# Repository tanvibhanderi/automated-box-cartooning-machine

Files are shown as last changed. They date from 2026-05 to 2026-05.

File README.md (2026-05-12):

# 📦 Automated Box Cartooning Machine
### Embedded Mechatronics System — Tiva C Microcontroller, Pneumatics, SolidWorks & AutoCAD









---

## 📌 Overview

A fully automated, low-cost **box cartooning machine** designed and built from scratch for small to medium-sized manufacturers. The system autonomously picks, rotates, folds, and locks cardboard box flaps using a custom-designed mechatronics system — all controlled by a single **TM4C123 microcontroller**.

Built for *MENG-2500 Mechatronics Project* at Humber Polytechnic — Winter 2025.

> 👩‍💻 **Author:** Tanvi Bhanderi — Mechatronics Engineering

---

## 🖼️ System Demo

| Physical Build | SolidWorks Assembly |
|---|---|
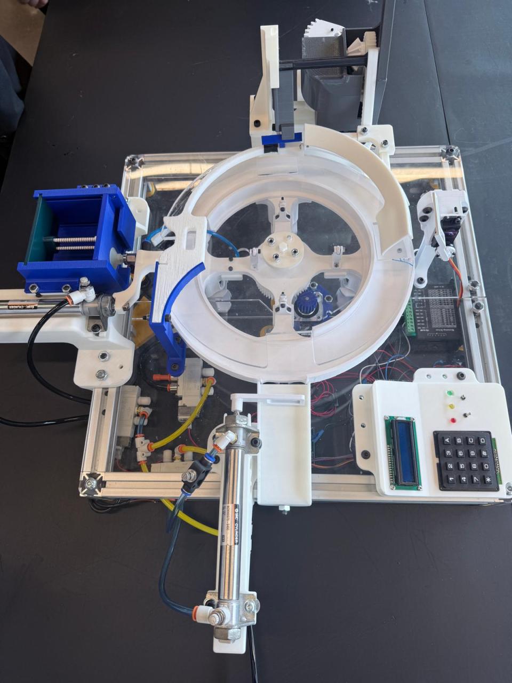
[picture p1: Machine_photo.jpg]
Machine
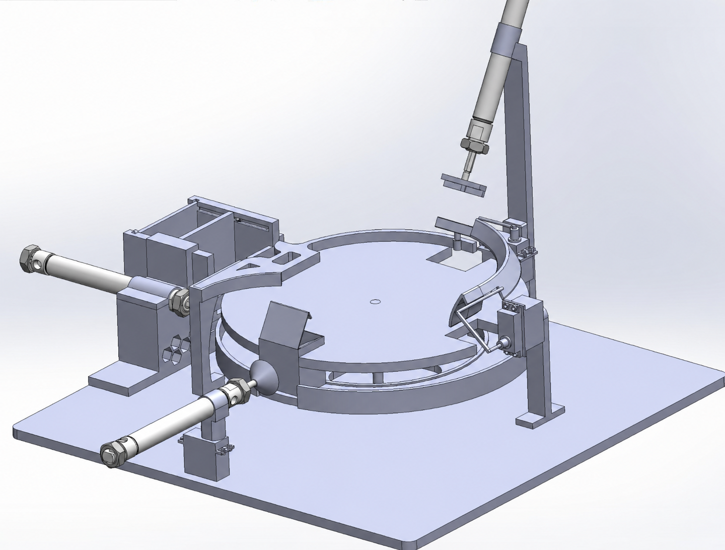
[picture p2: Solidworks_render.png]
CAD
|  |  |

---

## ✨ Key Features

- ✅ **4-phase automated operation** — pick, rotate, fold, lock
- ✅ **Closed-loop control** via ultrasonic sensor feedback
- ✅ **Operator interface** — 4×4 keypad + 16×2 I2C LCD display
- ✅ **Pneumatic actuation** — double-acting cylinders + vacuum suction cup
- ✅ **Custom SolidWorks design** — fully 3D printed and assembled
- ✅ **Under $300 budget** — scalable for real manufacturing use

---

## 🏗️ System Architecture

```
Operator Input (Keypad)
        │
        ▼
TM4C123GH6PM Microcontroller
        │
   ┌────┼──────────────────────────────┐
   │    │                              │
   ▼    ▼                              ▼
Stepper  Servo Motors (x2)      Solenoid Valves
Motor    (Flap Folding)         (Pneumatic Control)
   │                                   │
   ▼                                   ▼
Revolving Disc              Double-Acting Cylinders
(Box Transport)             + Venturi Vacuum Cup
                                       │
                            ┌──────────┴──────────┐
                            ▼                     ▼
                       Box Pickup            Box Ejection
                       
        ↑ Ultrasonic Sensor (HC-SR04) — position feedback
        ↑ LCD Display — status output
```

---

## ⚙️ 4-Phase Operation

| Phase | Action | Actuators Used |
|---|---|---|
| **Phase 1** | Box blank pickup from stack | Vacuum cup + pneumatic cylinder |
| **Phase 2** | Box transport & rotation | NEMA 17 stepper + revolving disc |
| **Phase 3** | Flap folding | MG996R servo motors |
| **Phase 4** | Flap locking & ejection | Pneumatic cylinder |

---

## 🔧 Technical Components

### Electrical

| Component | Part | Function |
|---|---|---|
| Microcontroller | TM4C123GH6PM (Tiva C) | Main logic & control |
| Stepper Motor | NEMA 17 + DM542 Driver | Revolving disc rotation |
| Servo Motors | MG996R (×2) | Flap folding mechanism |
| Sensor | HC-SR04 Ultrasonic | Object detection & positioning |
| Display | I2C LCD 16×2 | Status & user feedback |
| Input | 4×4 Matrix Keypad | Box count & operator control |
| Power | LM2596 Buck Converter | 5V regulation for logic components |
| Switching | 5V Relay Module | Solenoid valve control |

### Pneumatic

| Component | Spec | Function |
|---|---|---|
| Double-Acting Cylinders | Bore: 0.75in, Stroke: 4in | Box pickup & ejection |
| 5/2 Solenoid Valve | Spring return | Airflow direction control |
| Venturi Vacuum Generator | Compressed air powered | Suction generation |
| Flat Suction Cup | 25mm | Grips flat cardboard blank |

---

## 🖥️ SolidWorks Design

The full machine was designed in **SolidWorks** before fabrication. Parts were 3D printed and assembled on an aluminum extrusion frame.

### Assembly Structure

```
FINAL MAIN ASSEMB.SLDASM
├── REVOLVING DISC ASSEMB.SLDASM     — central rotating platform
├── PHASE_1.SLDASM                   — pickup mechanism
├── PHASE 2 ASSEMB.SLDASM            — transport & rotation
├── LOCK FOLDING ASSEMB.SLDASM       — flap folding arms
├── PHASE 4 ASSEMB.SLDASM            — ejection mechanism
├── BASE EXTRUSION ASSEMB.SLDASM     — aluminum frame base
└── CONTROL_INTERFACE.SLDPRT        — keypad/LCD panel
```

> The full SolidWorks assembly (`.SLDASM`) and all part files (`.SLDPRT`) are included in this repository.

---

## 📐 AutoCAD Manufacturing Drawings

All machine parts were drafted in **AutoCAD** for precise fabrication before being built. The `.DWG` files contain dimensioned 2D drawings used for laser cutting and CNC machining.

| File | Part |
|---|---|
| `final_box_cut_out.DWG` | Box blank cutout template |
| `MAIN_REVOLVING_DISC.DWG` | Central rotating disc |
| `LOWER_BASE_HALF.DWG` | Base plate — lower half |
| `LOWER_BASE_HALF_2.DWG` | Base plate — lower half variant |
| `TOP_BASE_CI_SIDE.DWG` | Top base — cylinder interface side |
| `TOP_BASE_MOTOR_SIDE.DWG` | Top base — motor mount side |
| `MOTOR_PLATE.DWG` | Stepper motor mounting plate |

---

## 📁 Repository Structure

```
📦 automated-box-cartooning-machine/
├── 📁 firmware/
│   └── main.c                       # Tiva C embedded C firmware
├── 📁 autocad/
│   ├── final_box_cut_out.DWG        # Box blank cutout template
│   ├── MAIN_REVOLVING_DISC.DWG      # Revolving disc drawing
│   ├── LOWER_BASE_HALF.DWG          # Base plate drawings
│   ├── LOWER_BASE_HALF_2.DWG
│   ├── TOP_BASE_CI_SIDE.DWG         # Top base drawings
│   ├── TOP_BASE_MOTOR_SIDE.DWG
│   └── MOTOR_PLATE.DWG              # Motor mount plate
├── 📁 assets/
│   ├── machine_photo.jpg            # Physical build photo
│   ├── solidworks_render.jpg        # SolidWorks assembly render
│   └── circuit_schematic.jpg        # Circuit wiring diagram
├── [SolidWorks .SLDPRT / .SLDASM files]
├── 📄 Final_Project_Report.pdf
└── 📄 README.md
```

> Open `FINAL MAIN ASSEMB.SLDASM` as the top-level SolidWorks assembly. Firmware compiles in Keil uVision or TI Code Composer Studio targeting TM4C123GH6PM.

---

## 🚀 Build & Flash Firmware

```bash
# Open in Keil uVision or TI Code Composer Studio
# Target: TM4C123GH6PM @ 16 MHz

# 1. Open firmware/main.c
# 2. Add TM4C123GH6PM.h to project (TI DriverLib or CMSIS)
# 3. Build → Flash via ICDI debugger on LaunchPad
```

**Key firmware functions:**

| Function | Description |
|---|---|
| `RotateMotor(angle, speed, dir)` | Steps NEMA 17 by exact degrees |
| `Servo_Set_Angle(pulse, pin)` | PWM bit-bang to MG996R servo |
| `DCV_Set(mask)` | Controls solenoid valves (active-low) |
| `Delay_MicroSecond(time)` | Hardware Timer1A precision delay |

---

- Designing a **multi-subsystem mechatronics machine** from concept to physical build
- Programming **embedded C++** on a TM4C123 microcontroller — timers, GPIO, PWM, UART
- Integrating **pneumatic systems** with electronic control — solenoid valves, cylinders, vacuum
- Building a full **SolidWorks assembly** with 40+ custom parts, designed for 3D printing
- Creating **AutoCAD manufacturing drawings** (`.DWG`) with dimensions for fabrication
- Implementing **closed-loop feedback** using ultrasonic sensors for position detection
- Working within a **$300 hardware budget** — component selection, sourcing, and tradeoffs

---

## 🔮 Future Improvements

- Add **IoT remote monitoring** for production tracking
- Implement **parameterized box sizing** — adjustable for multiple carton dimensions
- Replace open-loop stepper with **encoder feedback** for precise positioning
- Add **fault detection** — jam detection and automatic recovery logic

---

## 📚 References

- TM4C123GH6PM Datasheet — Texas Instruments
- MG996R Servo Datasheet — Tower Pro
- HC-SR04 Ultrasonic Sensor Datasheet — SparkFun
- NEMA 17 + DM542 Driver Documentation
- Humber Polytechnic MENG-2500 — Mechatronics Project, Winter 2025

---

<p align="center">
  Built by Tanvi Bhanderi · Humber Polytechnic — Mechatronics Engineering
</p>

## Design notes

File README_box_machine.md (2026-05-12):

# 📦 Automated Box Cartooning Machine
### Embedded Mechatronics System — TM4C123 Microcontroller, Pneumatics & SolidWorks








---

## 📌 Overview

A fully automated, low-cost **box cartooning machine** designed and built from scratch for small to medium-sized manufacturers. The system autonomously picks, rotates, folds, and locks cardboard box flaps using a custom-designed mechatronics system — all controlled by a single **TM4C123 microcontroller**.

Built for *MENG-2500 Mechatronics Project* at Humber Polytechnic — Winter 2025.

> 👩‍💻 **Author:** Tanvi Bhanderi — Mechatronics Engineering

---

## 🖼️ System Demo

| Physical Build | SolidWorks Assembly |
|---|---|
| Machine | CAD |

---

## ✨ Key Features

- **4-phase automated operation** — pick, rotate, fold, lock
- **Closed-loop control** via ultrasonic sensor feedback
- **Operator interface** — 4×4 keypad + 16×2 I2C LCD display
- **Pneumatic actuation** — double-acting cylinders + vacuum suction cup
- **Custom SolidWorks design** — fully 3D printed and assembled
- **Under $300 budget** — scalable for real manufacturing use

---

## 🏗️ System Architecture

```
Operator Input (Keypad)
        │
        ▼
TM4C123GH6PM Microcontroller
        │
   ┌────┼──────────────────────────────┐
   │    │                              │
   ▼    ▼                              ▼
Stepper  Servo Motors (x2)      Solenoid Valves
Motor    (Flap Folding)         (Pneumatic Control)
   │                                   │
   ▼                                   ▼
Revolving Disc              Double-Acting Cylinders
(Box Transport)             + Venturi Vacuum Cup
                                       │
                            ┌──────────┴──────────┐
                            ▼                     ▼
                       Box Pickup            Box Ejection
                       
        ↑ Ultrasonic Sensor (HC-SR04) — position feedback
        ↑ LCD Display — status output
```

---

## ⚙️ 4-Phase Operation

| Phase | Action | Actuators Used |
|---|---|---|
| **Phase 1** | Box blank pickup from stack | Vacuum cup + pneumatic cylinder |
| **Phase 2** | Box transport & rotation | NEMA 17 stepper + revolving disc |
| **Phase 3** | Flap folding | MG996R servo motors |
| **Phase 4** | Flap locking & ejection | Pneumatic cylinder |

---

## 🔧 Technical Components

### Electrical

| Component | Part | Function |
|---|---|---|
| Microcontroller | TM4C123GH6PM (Tiva C) | Main logic & control |
| Stepper Motor | NEMA 17 + DM542 Driver | Revolving disc rotation |
| Servo Motors | MG996R (×2) | Flap folding mechanism |
| Sensor | HC-SR04 Ultrasonic | Object detection & positioning |
| Display | I2C LCD 16×2 | Status & user feedback |
| Input | 4×4 Matrix Keypad | Box count & operator control |
| Power | LM2596 Buck Converter | 5V regulation for logic components |
| Switching | 5V Relay Module | Solenoid valve control |

### Pneumatic

| Component | Spec | Function |
|---|---|---|
| Double-Acting Cylinders | Bore: 0.75in, Stroke: 4in | Box pickup & ejection |
| 5/2 Solenoid Valve | Spring return | Airflow direction control |
| Venturi Vacuum Generator | Compressed air powered | Suction generation |
| Flat Suction Cup | 25mm | Grips flat cardboard blank |

---

## 🖥️ SolidWorks Design

The full machine was designed in **SolidWorks** before fabrication. Parts were 3D printed and assembled on an aluminum extrusion frame.

### Assembly Structure

```
FINAL MAIN ASSEMB.SLDASM
├── REVOLVING DISC ASSEMB.SLDASM     — central rotating platform
├── PHASE_1.SLDASM                   — pickup mechanism
├── PHASE 2 ASSEMB.SLDASM            — transport & rotation
├── LOCK FOLDING ASSEMB.SLDASM       — flap folding arms
├── PHASE 4 ASSEMB.SLDASM            — ejection mechanism
├── BASE EXTRUSION ASSEMB.SLDASM     — aluminum frame base
└── CONTROL_INTERFACE.SLDPRT        — keypad/LCD panel
```

> The full SolidWorks assembly (`.SLDASM`) and all part files (`.SLDPRT`) are included in this repository.

---

## 📁 Repository Structure

```
📦 automated-box-cartooning-machine/
├── 📁 firmware/
│   └── main.c                       # TM4C123 embedded C firmware — full machine control
├── 📁 solidworks/
│   └── FINAL_MAIN_ASSEMB.zip        # Complete SolidWorks assembly + all part files
├── 📁 assets/
│   ├── machine_photo.jpg            # Physical build photo
│   ├── solidworks_render.jpg        # SolidWorks assembly render
│   └── circuit_schematic.jpg        # Full circuit wiring diagram
├── 📄 Final_Project_Report.pdf      # Full project report
└── 📄 README.md
```

> Open `FINAL MAIN ASSEMB.SLDASM` as the top-level SolidWorks assembly. Firmware compiles in Keil uVision or TI Code Composer Studio targeting TM4C123GH6PM.

---

## 🚀 Build & Flash Firmware

```bash
# Open in Keil uVision or TI Code Composer Studio
# Target: TM4C123GH6PM @ 16 MHz

# 1. Open firmware/main.c
# 2. Add TM4C123GH6PM.h to project (TI DriverLib or CMSIS)
# 3. Build → Flash via ICDI debugger on LaunchPad
```

**Key firmware functions:**

| Function | Description |
|---|---|
| `RotateMotor(angle, speed, dir)` | Steps NEMA 17 by exact degrees |
| `Servo_Set_Angle(pulse, pin)` | PWM bit-bang to MG996R servo |
| `DCV_Set(mask)` | Controls solenoid valves (active-low) |
| `Delay_MicroSecond(time)` | Hardware Timer1A precision delay |

---

- Designing a **multi-subsystem mechatronics machine** from concept to physical build
- Programming **embedded C++** on a TM4C123 microcontroller — timers, GPIO, PWM, UART
- Integrating **pneumatic systems** with electronic control — solenoid valves, cylinders, vacuum
- Building a full **SolidWorks assembly** with 40+ custom parts, designed for 3D printing
- Implementing **closed-loop feedback** using ultrasonic sensors for position detection
- Working within a **$300 hardware budget** — component selection, sourcing, and tradeoffs

---

## 🔮 Future Improvements

- Add **IoT remote monitoring** for production tracking
- Implement **parameterized box sizing** — adjustable for multiple carton dimensions
- Replace open-loop stepper with **encoder feedback** for precise positioning
- Add **fault detection** — jam detection and automatic recovery logic

---

## 📚 References

- TM4C123GH6PM Datasheet — Texas Instruments
- MG996R Servo Datasheet — Tower Pro
- HC-SR04 Ultrasonic Sensor Datasheet — SparkFun
- NEMA 17 + DM542 Driver Documentation
- Humber Polytechnic MENG-2500 — Mechatronics Project, Winter 2025

---

<p align="center">
  Built by Tanvi Bhanderi · Humber Polytechnic — Mechatronics Engineering
</p>

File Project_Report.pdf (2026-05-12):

Course Number | MENG-2500
Course Title | Mechatronics Project
Semester/Year | 2025
Lab/Tutorial Report No. | Final Report
Title of the Experiment | Final Project Report
Instructor Name | Mehrdad Tabrizipour
Section No. | ONB
Submission Date | 4/22/2025
Due Date | 4/22/2025
Student Name | ID
TANVI BHANDERI | N01605037
GURSHAN SINGH | N01604467
HRISHIKESH PATEL | N01609756
ASSADULLAH JIN | N01626920
SOKRAT KRISTULLA | N01655524

* By signing above, you attest that you have contributed to this submission and confirm that all work you have contributed to this submission is your work. Any suspicion of copying or plagiarism in this work will result in an investigation of Academic Misconduct and may result in a ZERO on the work or possibly more severe penalties. https://academic-regulations.humber.ca/2021-2022/17.0-ACADEMIC-MISCONDUCT

## Introduction

### In manufacturing, automation is essential for increasing productivity and lowering human error. The goal of this project is to use embedded microcontroller devices to automate the box cartooning process. It targets manufacturers on a budget that are searching for a dependable and

scalable solution.

## Abstract

In this project, an automated cartooning machine that uses embedded technology is designed and put into operation. The objective is to create a small-scale, affordable solution for manufacturers. Pneumatic cylinders, a keypad, an LCD, sensors, servo motors, and a stepper motor are all controlled by a TM4C123GH6PM microcontroller. It has four operating phases and can automatically fold and lock box flaps. A closed-loop control

system is used by the machine to ensure accuracy and dependability.

## Problem Overview and Scope Statement

Manual box folding is labor-intensive, inconsistent, and inefficient in small to medium-sized businesses. The goal of this project is to create a device that uses actuators and sensor feedback to autonomously fold and lock box flaps. The solution needs to be small, flexible, and reasonably priced (within

a $300 budget).

## CODE

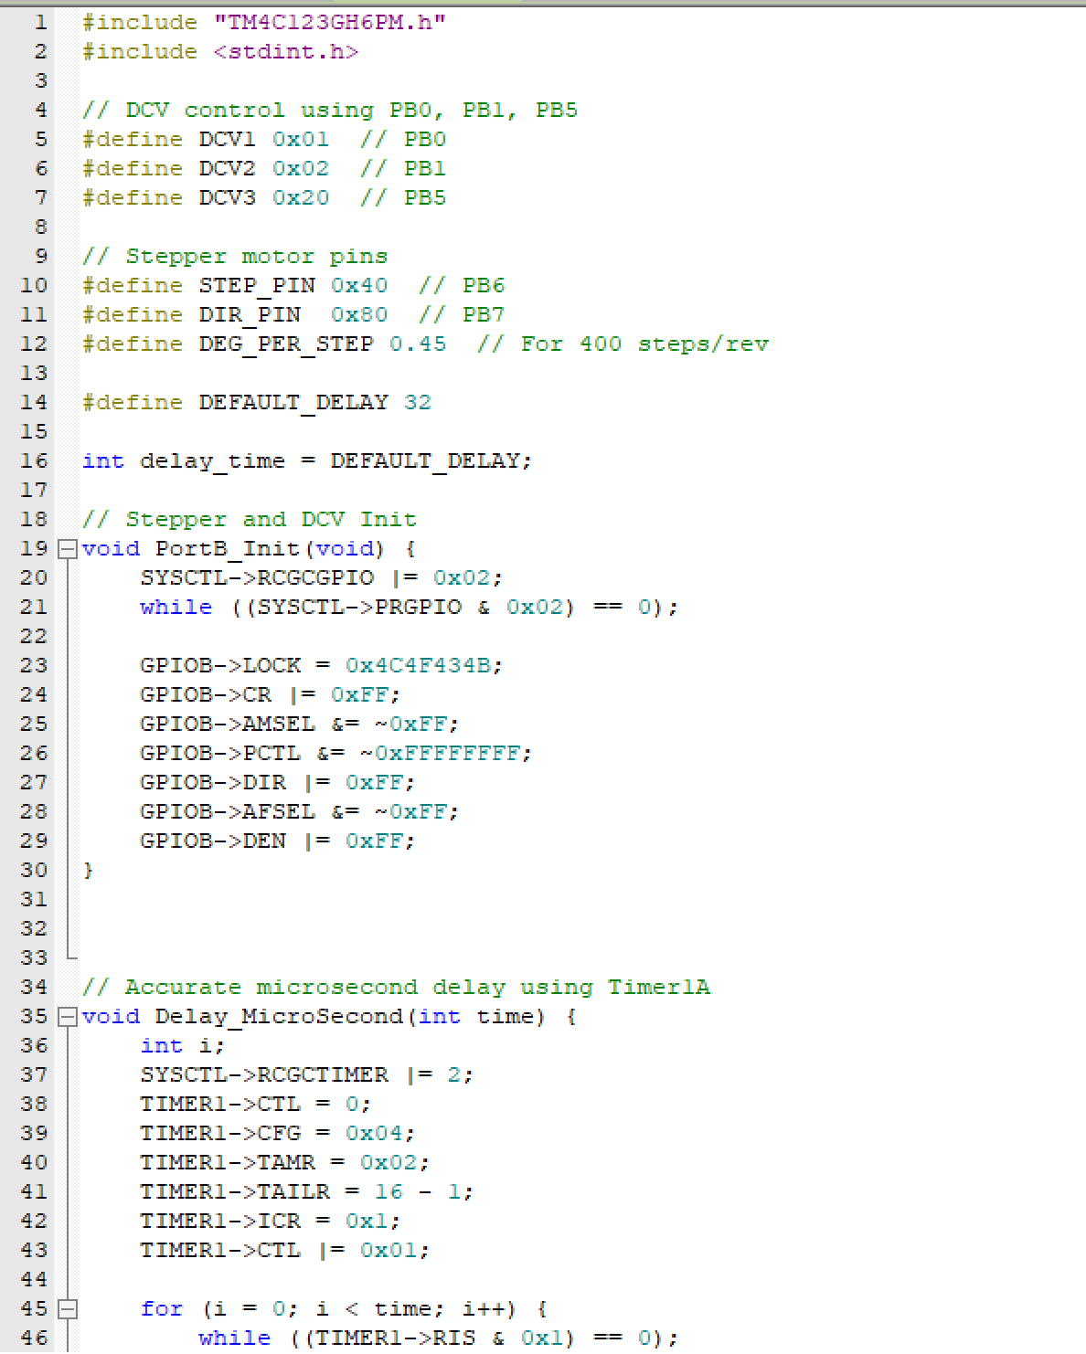
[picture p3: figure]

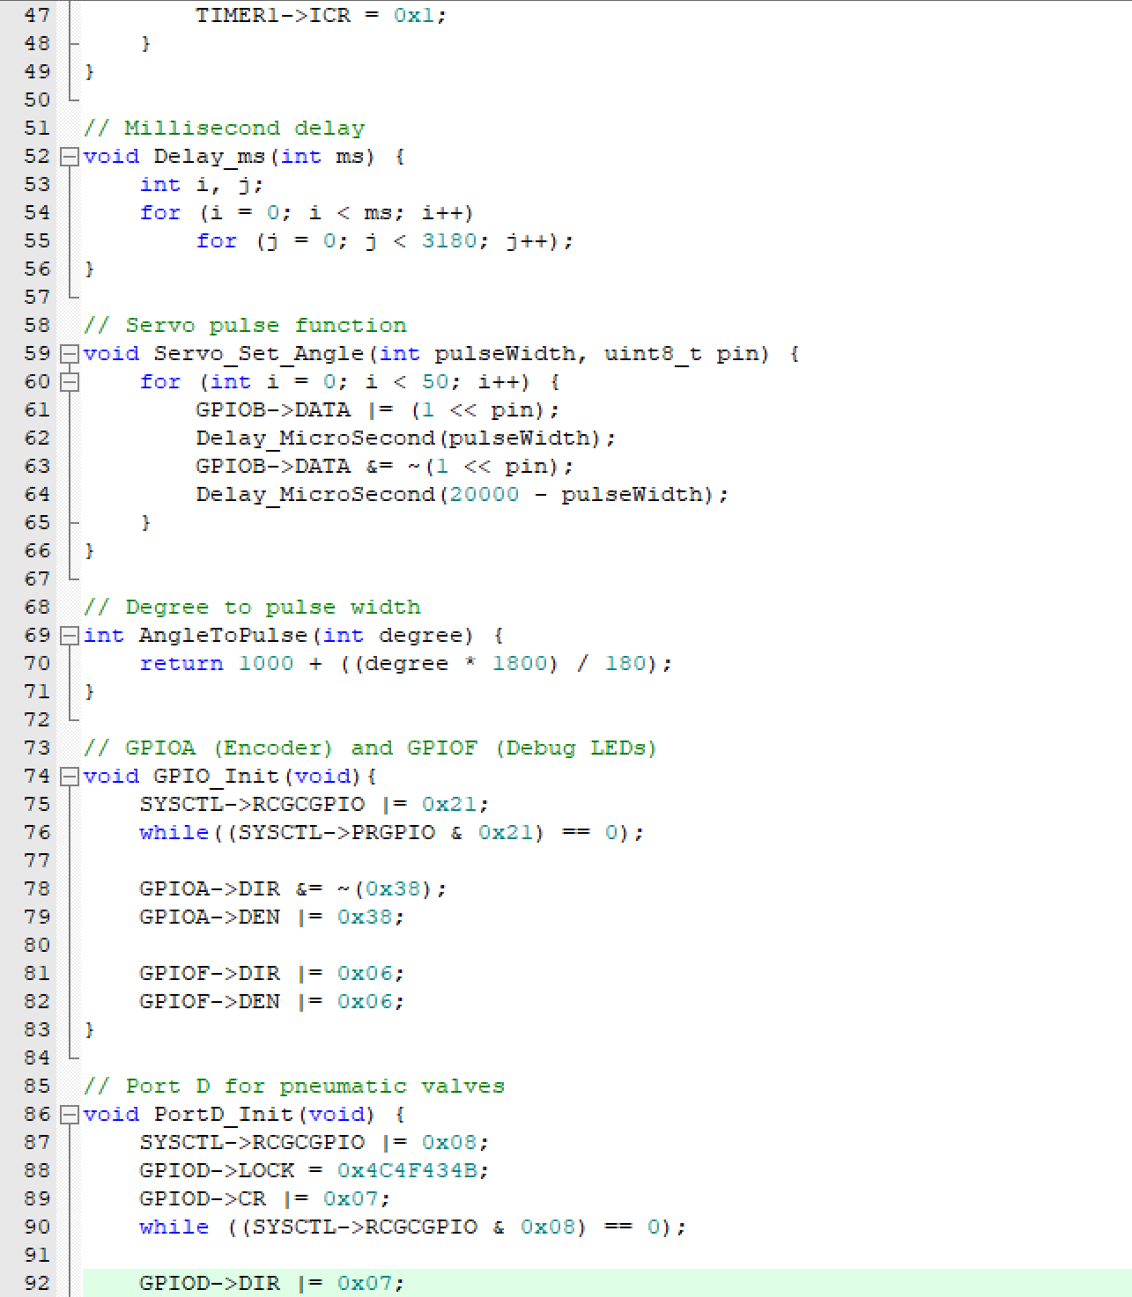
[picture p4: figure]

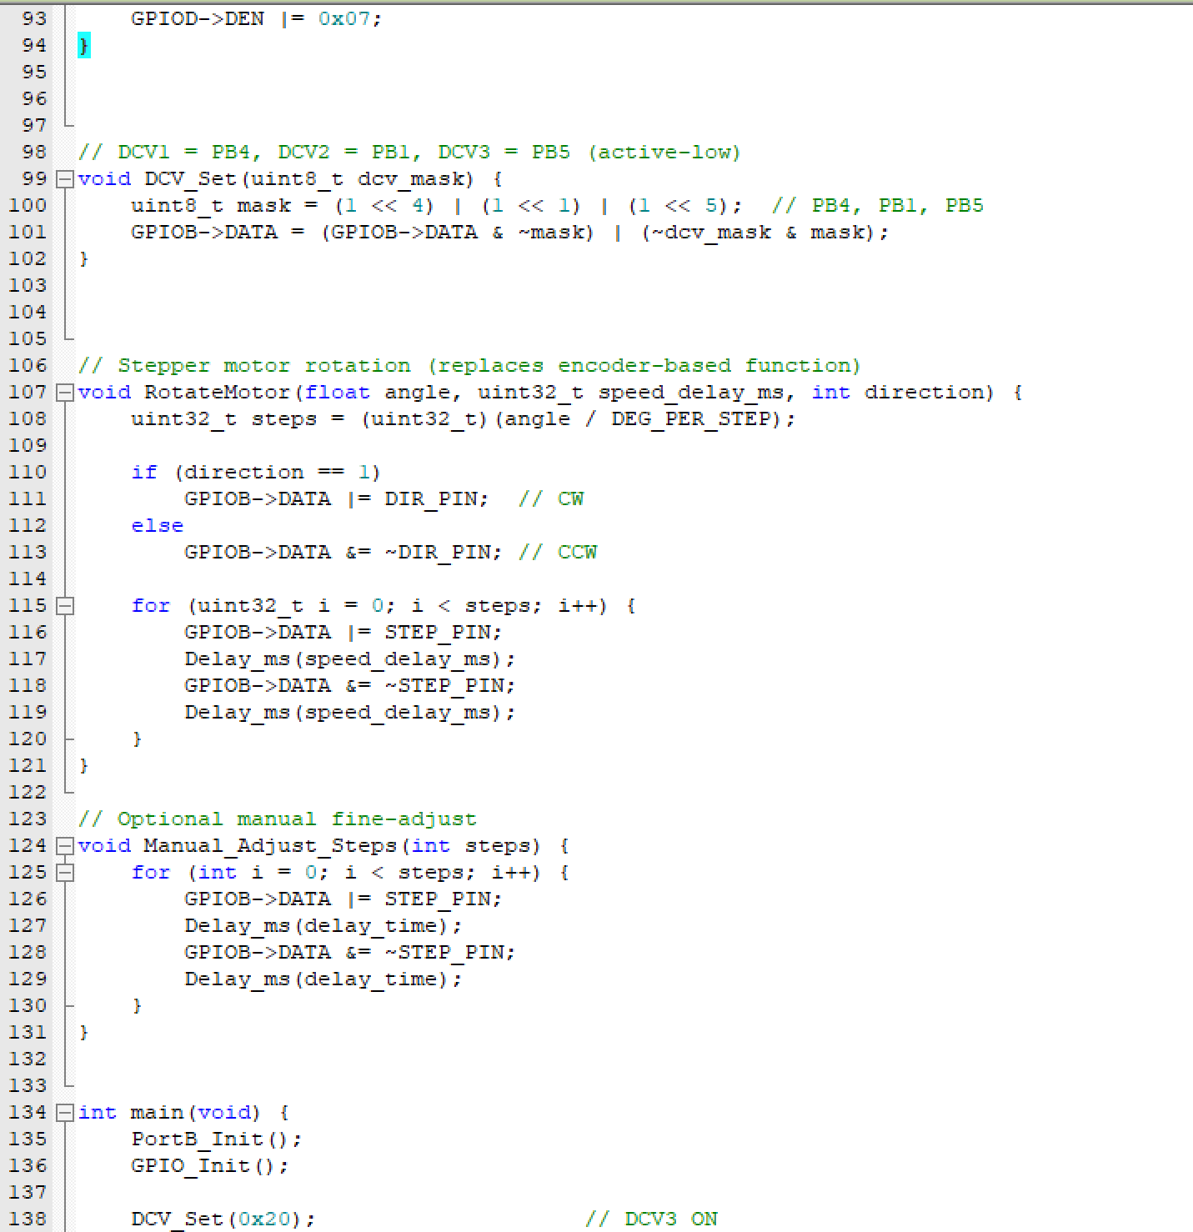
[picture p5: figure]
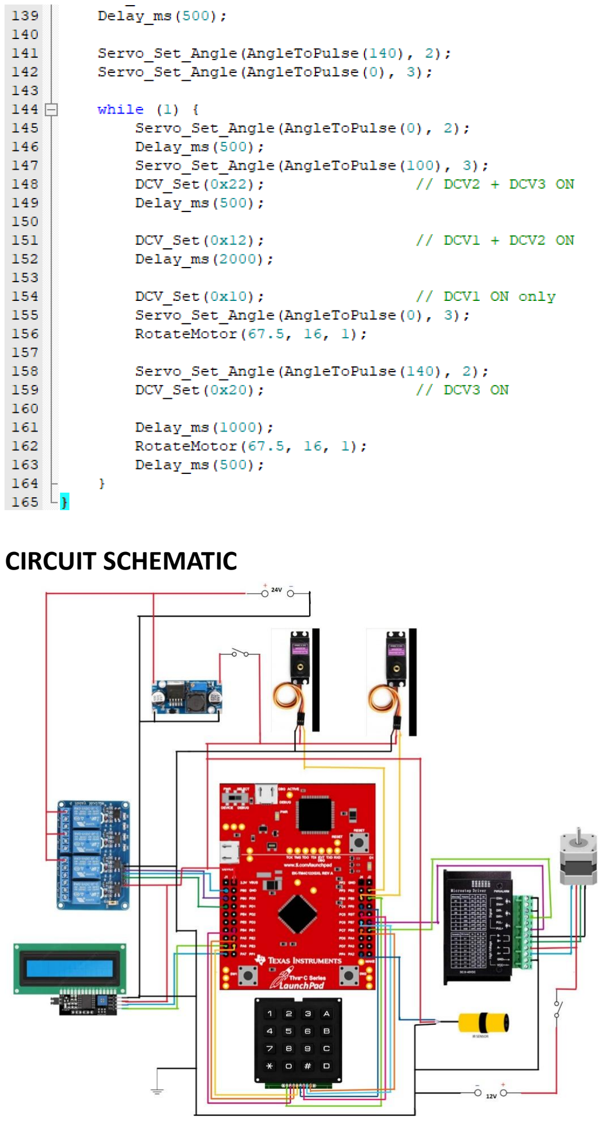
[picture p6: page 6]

## CIRCUIT SCHEMATIC

### 1. Electrical Components

### TIVA C LaunchPad (TM4C123GXL)

Function: Microcontroller board used for logic and control

Datasheet: https://www.ti.com/lit/ds/symlink/tm4c123gh6pm.pdf

Function: Controls solenoid valves and vacuum generator

Datasheet: https://www.circuitbasics.com/wp-content/uploads/2015/11/SRD-05VDC-SL-C-Datasheet.pdf (https://www.circuitbasics.com/wp-content/uploads/2015/11/SRD-05VDC-SL-C-Datasheet.pdf)

### MG996R Servo Motor

Function: Used for flap folding mechanism

Datasheet: https://www.electronicoscaldas.com/datasheet/MG996R_Tower-Pro.pdf

### 4x4 Matrix Keypad

Function: Used for inputting box count or control signals

Datasheet: https://cdn.sparkfun.com/assets/f/f/a/5/0/DS-16038.pdf

### I2C LCD Display (16x2)

Function: Displays status and user feedback

Datasheet: https://www.handsontec.com/dataspecs/module/I2C_1602_LCD.pdf

### NEMA 17 Stepper Motor

Function: Used for pushing or rotating boxes

Datasheet: https://pages.pbclinear.com/rs/909-BFY-775/images/Data-Sheet-Stepper-Motor-Support.pdf (https://pages.pbclinear.com/rs/909-BFY-775/images/Data-Sheet-Stepper-Motor-Support.pdf)

### Stepper Motor Driver (DM542)

Function: Drives the NEMA 17 motor

Datasheet: https: https://kitaez-cnc.com/f/dm542.pdf

### Ultrasonic Sensor (HC-SR04)

Function: Detects object presence or distance

Datasheet: https://cdn.sparkfun.com/datasheets/Sensors/Proximity/HCSR04.pdf

### LM2596 Buck Converter

Function: Steps down voltage to 5V for low-power components

Datasheet: https://www.ti.com/lit/ds/symlink/lm2596.pdf

### 2. Pneumatic Components

### Double-Acting Cylinders

Function: Used for pickup and ejection. Bore: 0.75in, Rod: 0.25in, Stroke: 4in

Datasheet: https://ngsgi.com/pdfs/cip_da_cylinders_specs.pdf

### 5/2 Solenoid Valve (Spring Return)

Function: Controls airflow direction for cylinder extension/retraction

Datasheet: https://www.uflowvalve.com/pneumatic-valve/product/5-2-single-solenoid-valvewith-spring-return (https://www.uflowvalve.com/pneumatic-valve/product/5-2-single-solenoid-valve-with-spring-return)

### Venturi Vacuum Generator

Function: Generates vacuum using compressed air for suction cup

Datasheet: https://cdn.norgren.com/pdf/CylindricalVenturiVacuumGenerators.pdf

### Flat Suction Cup (25mm)

Function: Grips flat paperboard carton using vacuum

Datasheet: https://www.vacmotion.com/Details.aspx?Cat=Suctioncups&Id=711

## Conclusion and Future Plans

This project effectively used embedded systems to create a cost-effective cartooning machine. It offers packaging applications a scalable automated option. Plans call for integrating IoT technologies for remote monitoring and using parameterized control logic to modify the design to fit different box

sizes.

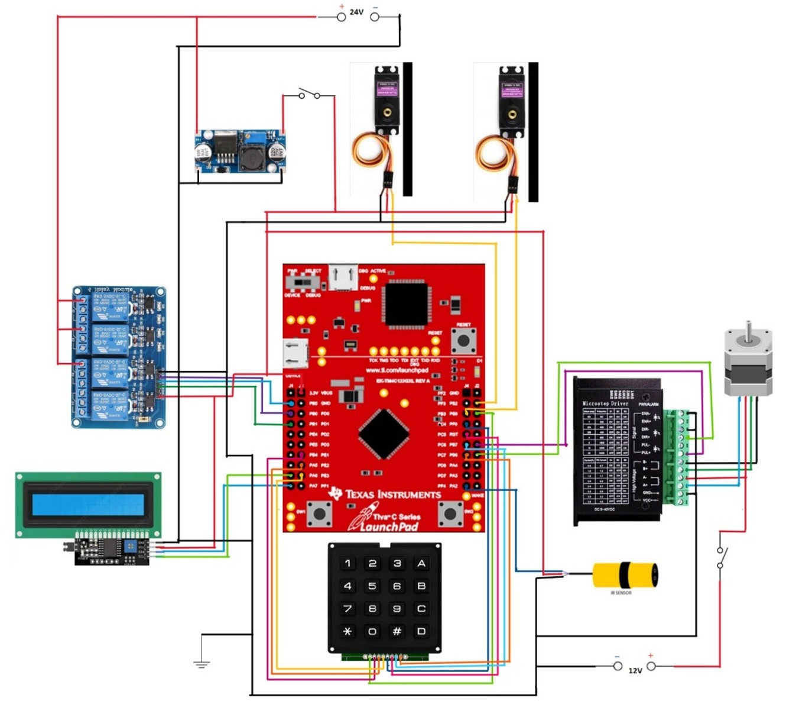
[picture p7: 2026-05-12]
circuit_schematic.jpg

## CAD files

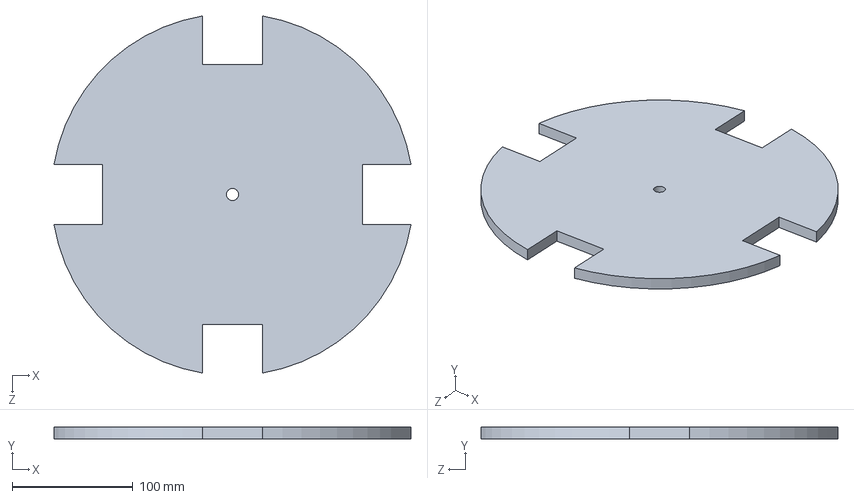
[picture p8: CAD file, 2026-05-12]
MAIN REVOLVING DISC.SLDPRT
295.8 x 10.0 x 295.8 mm

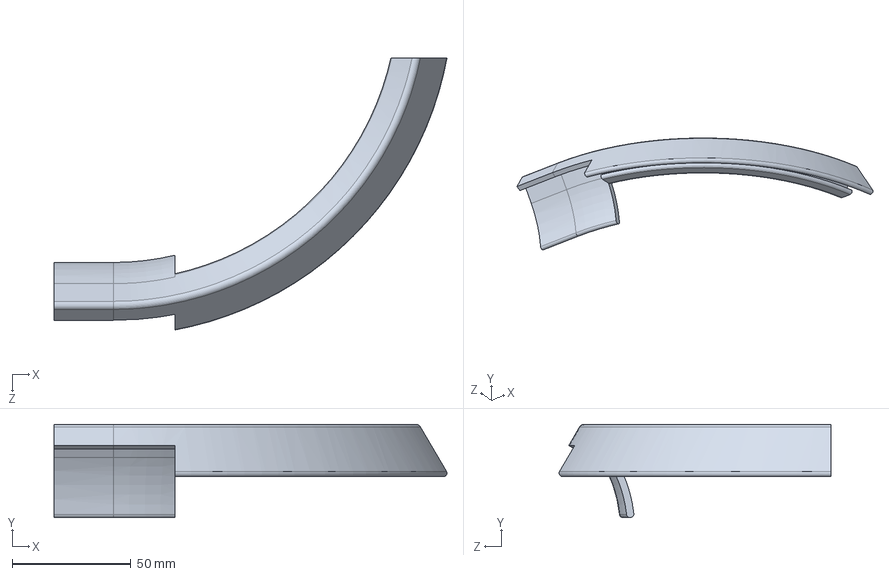
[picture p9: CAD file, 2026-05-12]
lock_folding.SLDPRT
165.4 x 39.2 x 114.4 mm

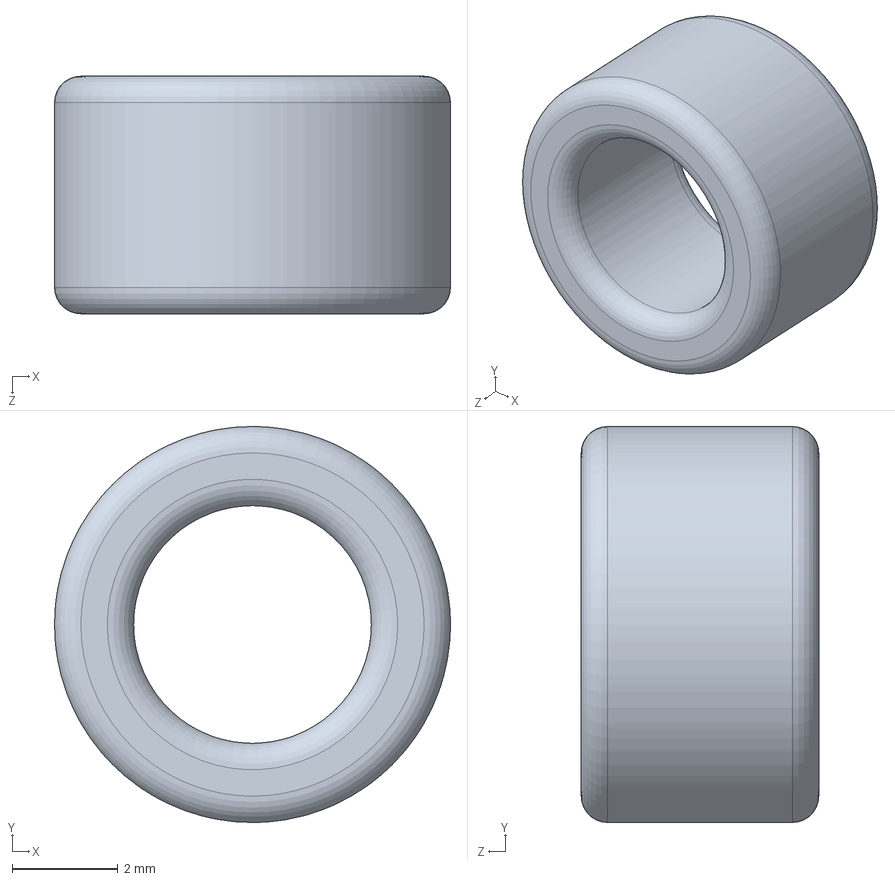
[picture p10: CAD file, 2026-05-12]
wheels.SLDPRT
7.50 x 7.50 x 4.50 mm

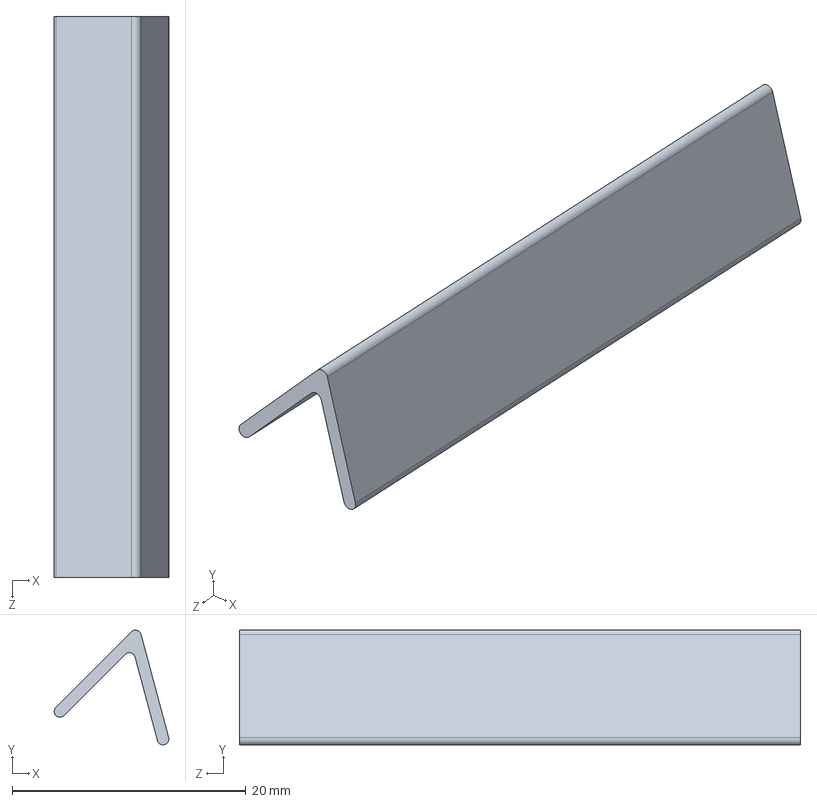
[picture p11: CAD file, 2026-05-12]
Part3.SLDPRT
9.82 x 9.82 x 48.0 mm

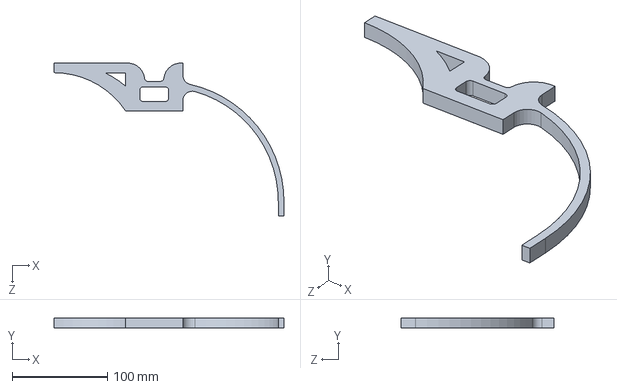
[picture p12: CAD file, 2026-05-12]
Part2.SLDPRT
241.0 x 10.0 x 160.0 mm

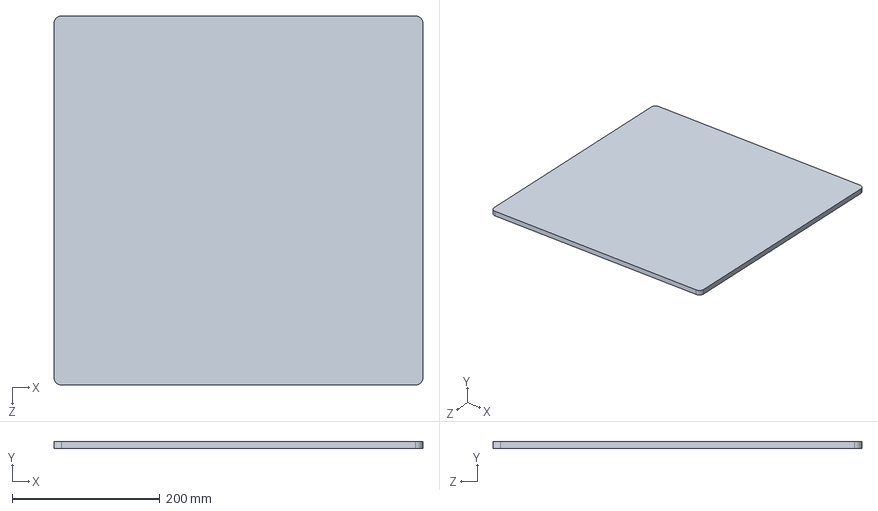
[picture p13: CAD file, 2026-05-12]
BASE PLATE.SLDPRT
500.0 x 10.0 x 500.0 mm

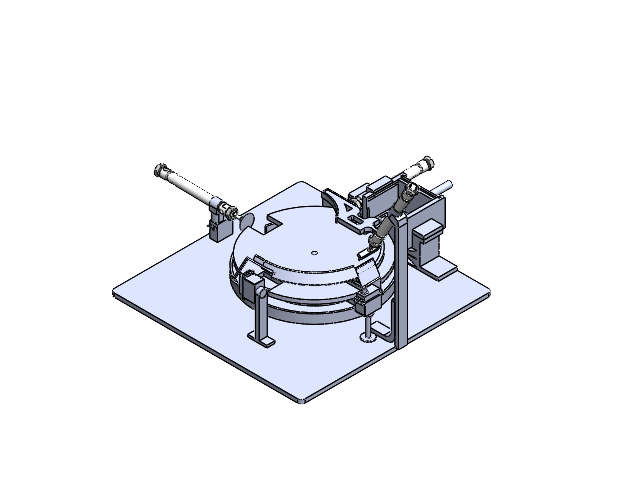
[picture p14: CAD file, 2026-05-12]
MAIN ASSEMBLY.SLDASM
BASE PLATE
MAIN REVOLVING DISC
Part6^MAIN ASSEMBLY
Part7^MAIN ASSEMBLY
Part11^MAIN ASSEMBLY
Part14^MAIN ASSEMBLY
Part15^MAIN ASSEMBLY
Part16^MAIN ASSEMBLY
Part17^MAIN ASSEMBLY x 2
Part26^MAIN ASSEMBLY
Part28^MAIN ASSEMBLY
Part29^MAIN ASSEMBLY
Part30^MAIN ASSEMBLY
Part31^MAIN ASSEMBLY
lock_folding
Part33^MAIN ASSEMBLY
Part35^MAIN ASSEMBLY
Part37^MAIN ASSEMBLY x 3
Part38^MAIN ASSEMBLY x 2
outer_cover
pushing_plate
wheels x 8
moving_plate
spring_cylinders
Part39^MAIN ASSEMBLY
Part40^MAIN ASSEMBLY
Part41^MAIN ASSEMBLY
Part42^MAIN ASSEMBLY
Part43^MAIN ASSEMBLY
Revolving Disc Support x 4
Part1^Stat Disc with Supports x 4
STATIC DISC

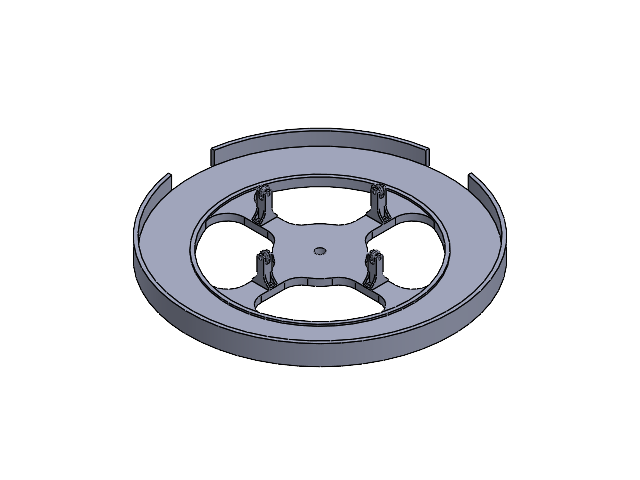
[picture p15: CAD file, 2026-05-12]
Stat Disc with Supports.SLDASM
Revolving Disc Support x 4
Part1^Stat Disc with Supports x 4
STATIC DISC

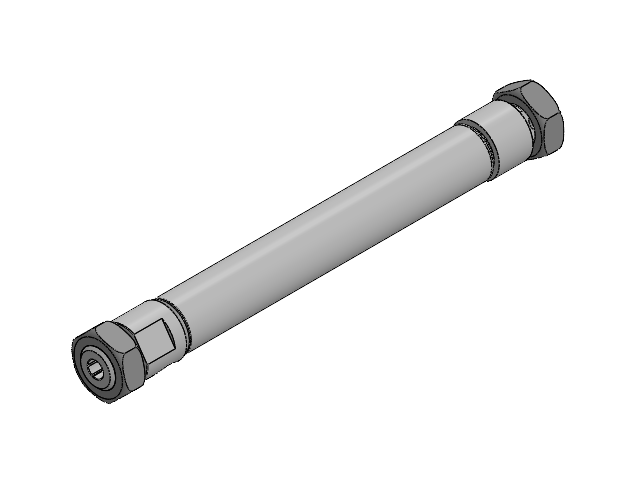
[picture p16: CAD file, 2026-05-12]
pneumatic cylinder.SLDASM


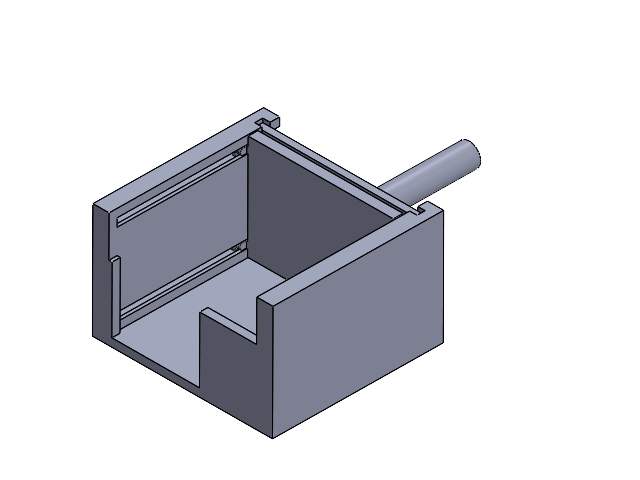
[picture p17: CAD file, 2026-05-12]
NEW_BOX_STACKER.SLDASM
outer_cover
pushing_plate

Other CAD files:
LOWER_BASE_HALF.DWG
LOWER_BASE_HALF_2.DWG
TOP_BASE_MOTOR_SIDE.DWG
MOTOR_PLATE.DWG
TOP_BASE_CI_SIDE.DWG
final box cut out.DWG
Revolving Disc Support.SLDPRT
moving_plate.SLDPRT
05870993_01.SLDPRT
05870993_02.SLDPRT
05870993_03.SLDPRT
05870993_04.SLDPRT
05870993_05.SLDPRT
05870993_06.SLDPRT
MAIN REVOLVING DISC.DWG
STATIC DISC.SLDPRT
outer_cover.SLDPRT
pushing_plate.SLDPRT
spring_cylinders.SLDPRT

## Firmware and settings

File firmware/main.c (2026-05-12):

/*
 * Automated Box Cartooning Machine — Firmware
 * Platform : TM4C123GH6PM (Tiva C LaunchPad)
 * Author   : Tanvi Bhanderi
 * Course   : MENG-2500 Mechatronics Project, Humber Polytechnic — Winter 2025
 *
 * Description:
 *   Controls a 4-phase automated box folding machine using:
 *   - NEMA 17 stepper motor (revolving disc transport)
 *   - MG996R servo motors x2 (flap folding)
 *   - 3x pneumatic DCV solenoid valves (pickup & ejection)
 *   - Venturi vacuum generator (suction cup)
 *
 * Pin Mapping:
 *   Port B: Stepper (PB6=STEP, PB7=DIR), DCVs (PB0, PB1, PB5)
 *   Port A: Encoder inputs (PA3, PA4, PA5)
 *   Port D: Pneumatic valve outputs (PD0, PD1, PD2)
 *   Port F: Debug LEDs (PF1, PF2)
 *
 * Operation Cycle:
 *   Phase 1 → Box pickup (piston + vacuum)
 *   Phase 2 → Flap pre-fold (servo arms flatten top flaps)
 *   Phase 3 → Lid close (servo L-rod presses lid down)
 *   Phase 4 → Box ejection (cylinder + suction cup removes box)
 *   → Disc resets → Repeat
 *
 * Build: Keil uVision / TI Code Composer Studio
 */

#include "TM4C123GH6PM.h"
#include <stdint.h>

// ─────────────────────────────────────────────
// Pin Definitions
// ─────────────────────────────────────────────

// DCV solenoid valves — Port B (active-low)
#define DCV1  0x01   // PB0 — vacuum/pickup cylinder
#define DCV2  0x02   // PB1 — ejection cylinder
#define DCV3  0x20   // PB5 — flap fold cylinder

// Stepper motor — Port B
#define STEP_PIN     0x40   // PB6
#define DIR_PIN      0x80   // PB7
#define DEG_PER_STEP 0.45   // For 400 steps/rev (half-step mode)

// Timing
#define DEFAULT_DELAY 32

// ─────────────────────────────────────────────
// Global Variables
// ─────────────────────────────────────────────
int delay_time = DEFAULT_DELAY;

// ─────────────────────────────────────────────
// Port B Init — Stepper motor + DCV solenoids
// ─────────────────────────────────────────────
void PortB_Init(void) {
    SYSCTL->RCGCGPIO |= 0x02;
    while ((SYSCTL->PRGPIO & 0x02) == 0);

    GPIOB->LOCK  =  0x4C4F434B;
    GPIOB->CR   |=  0xFF;
    GPIOB->AMSEL &= ~0xFF;
    GPIOB->PCTL  &= ~0xFFFFFFFF;
    GPIOB->DIR  |=  0xFF;
    GPIOB->AFSEL &= ~0xFF;
    GPIOB->DEN  |=  0xFF;
}

// ─────────────────────────────────────────────
// Port D Init — Pneumatic valve outputs
// ─────────────────────────────────────────────
void PortD_Init(void) {
    SYSCTL->RCGCGPIO |= 0x08;
    GPIOD->LOCK  =  0x4C4F434B;
    GPIOD->CR   |=  0x07;
    while ((SYSCTL->RCGCGPIO & 0x08) == 0);

    GPIOD->DIR  |=  0x07;
    GPIOD->DEN  |=  0x07;
}

// ─────────────────────────────────────────────
// GPIO Init — Encoder inputs (Port A) + Debug LEDs (Port F)
// ─────────────────────────────────────────────
void GPIO_Init(void) {
    SYSCTL->RCGCGPIO |= 0x21;
    while ((SYSCTL->PRGPIO & 0x21) == 0);

    // Port A — encoder inputs (PA3, PA4, PA5)
    GPIOA->DIR  &= ~(0x38);
    GPIOA->DEN  |=  0x38;

    // Port F — debug LEDs (PF1=Red, PF2=Blue)
    GPIOF->DIR  |=  0x06;
    GPIOF->DEN  |=  0x06;
}

// ─────────────────────────────────────────────
// Microsecond Delay — Timer1A hardware timer
// ─────────────────────────────────────────────
void Delay_MicroSecond(int time) {
    int i;
    SYSCTL->RCGCTIMER |= 2;
    TIMER1->CTL   = 0;
    TIMER1->CFG   = 0x04;
    TIMER1->TAMR  = 0x02;
    TIMER1->TAILR = 16 - 1;
    TIMER1->ICR   = 0x1;
    TIMER1->CTL  |= 0x01;

    for (i = 0; i < time; i++) {
        while ((TIMER1->RIS & 0x1) == 0);
        TIMER1->ICR = 0x1;
    }
}

// ─────────────────────────────────────────────
// Millisecond Delay — Software loop
// ─────────────────────────────────────────────
void Delay_ms(int ms) {
    int i, j;
    for (i = 0; i < ms; i++)
        for (j = 0; j < 3180; j++);
}

// ─────────────────────────────────────────────
// Servo Control — PWM pulse via bit-banging
// pulseWidth: microseconds (1000=0°, 2000=180°)
// pin: GPIOB bit position (2=PB2, 3=PB3)
// ─────────────────────────────────────────────
void Servo_Set_Angle(int pulseWidth, uint8_t pin) {
    for (int i = 0; i < 50; i++) {
        GPIOB->DATA |=  (1 << pin);
        Delay_MicroSecond(pulseWidth);
        GPIOB->DATA &= ~(1 << pin);
        Delay_MicroSecond(20000 - pulseWidth);
    }
}

// ─────────────────────────────────────────────
// Angle to Pulse Width Conversion
// Maps 0–180° → 1000–2800 µs
// ─────────────────────────────────────────────
int AngleToPulse(int degree) {
    return 1000 + ((degree * 1800) / 180);
}

// ─────────────────────────────────────────────
// DCV Solenoid Valve Control (active-low)
// dcv_mask: bitmask of valves to activate
// ─────────────────────────────────────────────
void DCV_Set(uint8_t dcv_mask) {
    uint8_t mask = (1 << 4) | (1 << 1) | (1 << 5);   // PB4, PB1, PB5
    GPIOB->DATA = (GPIOB->DATA & ~mask) | (~dcv_mask & mask);
}

// ─────────────────────────────────────────────
// Stepper Motor Rotation
// angle: degrees to rotate
// speed_delay_ms: step delay (lower = faster)
// direction: 1=CW, 0=CCW
// ─────────────────────────────────────────────
void RotateMotor(float angle, uint32_t speed_delay_ms, int direction) {
    uint32_t steps = (uint32_t)(angle / DEG_PER_STEP);

    if (direction == 1)
        GPIOB->DATA |=  DIR_PIN;   // Clockwise
    else
        GPIOB->DATA &= ~DIR_PIN;   // Counter-clockwise

    for (uint32_t i = 0; i < steps; i++) {
        GPIOB->DATA |=  STEP_PIN;
        Delay_ms(speed_delay_ms);
        GPIOB->DATA &= ~STEP_PIN;
        Delay_ms(speed_delay_ms);
    }
}

// ─────────────────────────────────────────────
// Manual Fine-Adjust (keypad tuning)
// ─────────────────────────────────────────────
void Manual_Adjust_Steps(int steps) {
    for (int i = 0; i < steps; i++) {
        GPIOB->DATA |=  STEP_PIN;
        Delay_ms(delay_time);
        GPIOB->DATA &= ~STEP_PIN;
        Delay_ms(delay_time);
    }
}

// ─────────────────────────────────────────────
// Main — 4-Phase Cartooning Cycle
// ─────────────────────────────────────────────
int main(void) {

    // Initialize all peripherals
    PortB_Init();
    GPIO_Init();
    PortD_Init();

    // ── Startup: DCV3 ON (vacuum ready), servos to home position ──
    DCV_Set(0x20);                          // DCV3 ON — vacuum ON
    Delay_ms(500);
    Servo_Set_Angle(AngleToPulse(140), 2);  // Servo 1 → home (140°)
    Servo_Set_Angle(AngleToPulse(0),   3);  // Servo 2 → home (0°)

    // ── Main Operation Loop ──
    while (1) {

        // ── PHASE 1: Box Pickup ──────────────────────────────────
        // Servo 1 opens, Servo 2 pre-positions
        // DCV2 + DCV3 activate: vacuum + pickup cylinder extends
        Servo_Set_Angle(AngleToPulse(0),   2);   // Servo 1 open
        Delay_ms(500);
        Servo_Set_Angle(AngleToPulse(100), 3);   // Servo 2 pre-position
        DCV_Set(0x22);                            // DCV2 + DCV3 ON
        Delay_ms(500);

        // ── PHASE 2: Flap Pre-Fold ───────────────────────────────
        // DCV1 + DCV2 activated: cylinder pushes box onto disc
        // Flap arms flatten top flaps without sealing
        DCV_Set(0x12);                            // DCV1 + DCV2 ON
        Delay_ms(2000);

        // ── PHASE 3: Lid Close ───────────────────────────────────
        // Servo L-rod presses lid down, disc rotates 67.5°
        DCV_Set(0x10);                            // DCV1 ON only
        Servo_Set_Angle(AngleToPulse(0),   3);   // Servo 2 lid press
        RotateMotor(67.5, 16, 1);                 // Disc rotates CW 67.5°

        // ── PHASE 4: Box Ejection ────────────────────────────────
        // Servo 1 closes, DCV3 reactivates for ejection cylinder
        // Disc resets for next cycle
        Servo_Set_Angle(AngleToPulse(140), 2);   // Servo 1 close
        DCV_Set(0x20);                            // DCV3 ON — ejection

        Delay_ms(1000);
        RotateMotor(67.5, 16, 1);                 // Disc resets
        Delay_ms(500);

        // ── Cycle complete → restart from Phase 1 ──
    }
}

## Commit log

2026-05-12 SolidWorks part and assembly files
    [05870993_01.SLDPRT, 05870993_02.SLDPRT, 05870993_03.SLDPRT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]
2026-05-12 AutoCAD manufacturing drawings
    [LOWER_BASE_HALF.DWG, LOWER_BASE_HALF_2.DWG, MAIN REVOLVING DISC.DWG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]
